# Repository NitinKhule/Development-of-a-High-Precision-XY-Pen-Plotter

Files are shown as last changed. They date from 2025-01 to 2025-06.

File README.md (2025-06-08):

## 🖊️ XY Pen Plotter – Mechatronics System Development

A functional XY Pen Plotter developed through the integration of mechanical design, embedded programming, and control system logic, following the V-model engineering lifecycle.

---

### 🛠️ Key Contributions

- ⚙️ **Mechanical Design & Fabrication**  
  ➤ Designed precise **CAD models** in SolidWorks  
  ➤ Fabricated custom parts using **3D printing** for optimized fit and high mechanical precision  

- 🧠 **Embedded System Programming**  
  ➤ Programmed the **ESP32 microcontroller** to manage:  
  - Stepper motor motion control  
  - Pen actuation routines  
  - Full system automation and calibration workflows  

- 🚧 **Hardware Optimization & Troubleshooting**  
  ➤ Solved key integration issues such as:  
  - **Wire routing and cable management**  
  - **Sensor noise filtering** for stable operation  
  ➤ Performed rigorous **testing and tuning** for consistent output quality  

- 🤝 **Multidisciplinary Collaboration**  
  ➤ Collaborated in a **cross-functional team** to:  
  - Assemble mechanical structures  
  - Design electrical circuits  
  - Fine-tune system-level performance and user interaction  

- 📐 **System Architecture – V-Model Application**  
  ➤ Followed the **V-model framework** for development:  
  - Requirements capture → Design → Implementation → Validation  
  - Ensured systematic traceability and modular development

---

### 🔧 Tools & Technologies Used
- SolidWorks (3D CAD Modeling)  
- ESP32 Microcontroller (Wi-Fi + Motion Control)  
- Stepper Motors, Drivers, and End Sensors  
- Arduino IDE · Embedded C  
- 3D Printing (PLA/FDM)  
- V-Model Software Development Lifecycle

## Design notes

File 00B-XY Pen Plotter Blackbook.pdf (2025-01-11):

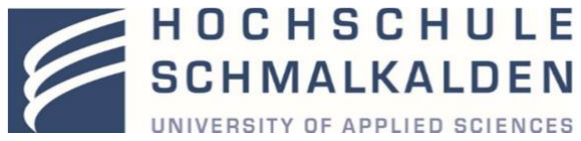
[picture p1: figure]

Schmalkalden University of Applied Sciences

Project Report on
XY- Pen Plotter

In partial fulfilment of the requirements for the degree of

Master of Engineering in
Mechatronics and Robotics

Under the subject of:
Workshop Mechatronics

Submitted By:

Choudhary, Prithviraj | 315448
Gangiredla, Varun Kumar | 315461
Khule, Nitin | 315513
Pandaraboyana, Dheeraj Kumar | 315535
Rao, Parul Vivek Sunder | 315476

Department of Mechanical Engineering Schmalkalden University of Applied Sciences Blechhammer 9, 98574 Schmalkalden

Dec 2023

CERTIFICATE

This is to certify that the project titled “XY Pen plotter” submitted by Choudhary Prithviraj, Gangiredla Varun Kumar, Khule Nitin, Pandaraboyana Dheeraj Kumar, Rao Parul Vivek Sunder; to the Mechanical Engineering Department of Schmalkalden University of Applied Sciences, in partial fulfilment of the requirements for the award of the degree of Master of Engineering in Mechatronics and Robotics is a record of our own work.

To the best of my knowledge, this report has not been submitted to any other University or Institute for award of any degree.

Choudhary, Prithviraj | 315448
Gangiredla, Varun Kumar | 315461
Khule, Nitin | 315513
Pandaraboyana, Dheeraj Kumar | 315535
Rao, Parul Vivek Sunder | 315476

This is to certify that the statements made by the candidate are correct to the best of our knowledge and belief. It is further understood that by this certificate the undersigned do not endorse or approve any statement made, opinion expressed or conclusion drawn herein, but approve the report only for the purpose for which it is submitted.

Countersigned:

Prof. Dr.-Ing. Stefan Roth, Professur Produktentwicklung / Konstruktion
Angewandte Kunststofftechnik (AKT), Fakultät Maschinenbau, Hochschule Schmalkalden,
Blechhammer 9, 98574 Schmalkalden

Prof. Dr.-Ing. Silvio Bachmann, Assistant Professor & Coordinator, Fakultät Elektrotechnik,
Hochschule Schmalkalden,
Blechhammer 9, 98574 Schmalkalden

ACKNOWLEDGEMENT

It gives us immense pleasure to express deep sense of gratitude to our supervisors

Prof. Dr.-Ing. Silvio Bachmann & Prof. Dr. Stefan Roth, for their whole hearted

and invaluable guidance throughout the project work. Without their sustained and

sincere effort, this project work would not have taken this shape. They encouraged and

helped us to overcome various difficulties that we have faced at various stages of our

project work.

We would like to take this opportunity to thank our teachers for providing a great

support and education to us in completing our workshop and for giving us the

opportunity to complete the project.

We would also like to thank our colleagues in our class because it was a great

experience to interact with them and their doubts in the class made us understand

the subject better. Last but not the least, many thanks to all group members, we

together had an amazing experience where we learned from each other, which at last

gave us great results.

Finally, we would like to thank all of our friends, family members and almighty for

their continuous help and encouragement.

TABLE OF CONTENTS

List of Figures | Pg. No.
Figure 1.1 Pen Plotter | 7
Figure 2.1 Nikolaus Haus | 8
Figure 2.2 Organisation Chart | 9
Figure 2.3 V-Model | 11
Figure 2.4 Morphological Chart | 12
Figure 3.1 DC Motor | 13
Figure 3.2 ESP32 Board | 13
Figure 3.3 L298N Motor Driver | 13
Figure 3.4 Linear Ball Bearing | 14
Figure 3.5 Pulley | 14
Figure 3.6 Adapter | 14
Figure 3.7 GT2 Belt | 14
Figure 3.8 Fastener | 15
Figure 3.9 Limit Switch | 15
Figure 3.10 MOSFET Switch | 15
Figure 3.11 Hall Sensor | 16
Figure 3.12 DC-DC Voltage Converter | 16
Figure 3.13 Kill Switch | 16
Figure 3.14 Electric Circuit Diagram | 17
Figure 3.15 Electronic Enclosure | 18
Figure 3.16 CAD Design | 19
Figure 3.17 Pen Holder | 20
Figure 3.18 End Effector | 20
Figure 3.19 Foot Design | 21
Figure 3.20 DC Motor Mount | 21
Figure 3.21 Pully Mount | 22
Figure 3.22 Sliding Pully Mount | 22
Figure 3.23 Storage Compartment | 23
Figure 4.1 3D Printer | 24
Figure 4.2 Test Piece | 25
Figure 4.3 Wires and Cables | 26
Figure 4.4 Raw v/s Filtered Data | 27

List of Tables | Pg. No.
Table 2.1 Project Timeline | 10
Table 5.1 Verification Protocol | 29
Table 5.2 Verification Report | 31
Table 5.3 Validation Protocol | 32
Table 5.4 Validation Report | 33
Table 6.1 Bill of Material | 35

## 1. INTRODUCTION

1.1 OBJECTIVES

We take great pleasure in presenting the comprehensive project report documenting our group's remarkable achievement in the development of a pen plotter. Our endeavour was dedicated to the creation of a sophisticated pen plotter capable of producing intricate drawings, with a specific emphasis on the renowned Nikolaus Haus. This project report meticulously details our journey, providing an exhaustive account of the design process, implementation strategies, testing protocols, and the successful realization of our pen plotter project.

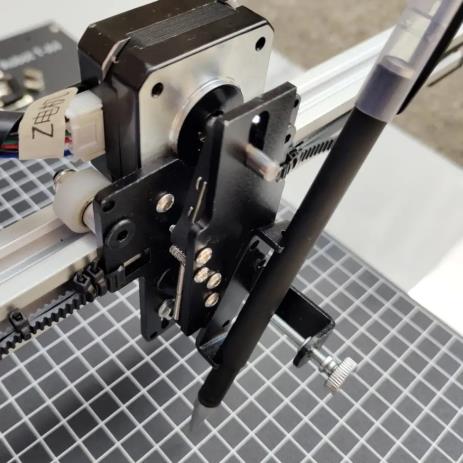
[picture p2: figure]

Figure 1.1 Pen Plotter

The Nikolaus Haus, renowned for its complex architectural details and artistic significance, posed a compelling challenge. Our sole objective was to engineer a pen plotter capable of faithfully reproducing the intricate features of the Nikolaus Haus.

The design phase involved a thorough exploration of hardware, software, and mechanical components. We meticulously selected motors, sensors, and control mechanisms to ensure optimal accuracy and control. Our software development efforts focused on designing and implementing sophisticated algorithms capable of interpreting drawing sequences and translating them into precise pen movements.

Testing and evaluation played a pivotal role in validating the performance of our pen plotter. Rigorous tests were conducted to measure accuracy, speed, and overall capability in recreating the Nikolaus Haus. Through detailed analysis of test results and iterative improvements, we ensured that our pen plotter consistently delivered exceptional results, capturing the essence of the Nikolaus Haus in each stroke.

This project report offers an in-depth narrative of our journey, elucidating the design process, implementation strategies, testing methodologies, and the final outcome of our pen plotter project. It stands as a testament to our commitment to innovation, precision, and admiration for architectural marvels that serve as sources of inspiration. We aspire for our work not only to contribute to the advancement of pen plotting but also to ignite further exploration and creativity in the realms of architectural representation and artistic expression.

## 2. PROJECT GOALS AND PROJECT PLANNING

2.1 PROJECT GOALS AND OBJECTIVES

The main goal of this project is to construct and advance a pen plotter by integrating various components responsible for governing pen movement and ensuring precise plotting on paper. The project team will engage in tasks such as designing, fabricating, and assembling the pen plotter, programming the control system, and establishing a user-friendly interface. The key activities encompass:

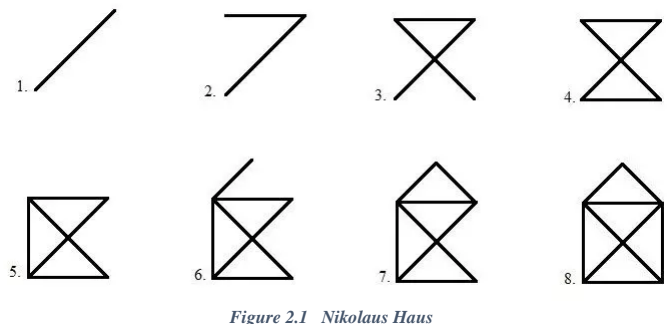
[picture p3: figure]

Figure 2.1 Nikolaus Haus

- Identifying user requirements and subsequently formulating technical and design specifications.
- Executing hardware, software, electrical, and mechanical CAD designs.
- Creating a user interface to manage pen movement.
- Conducting thorough testing and calibration of the pen plotter to achieve optimal performance.
- Demonstrating the pen plotter's functionality and showcasing its output through plotted designs, with a specific focus on Nikolaus Haus.

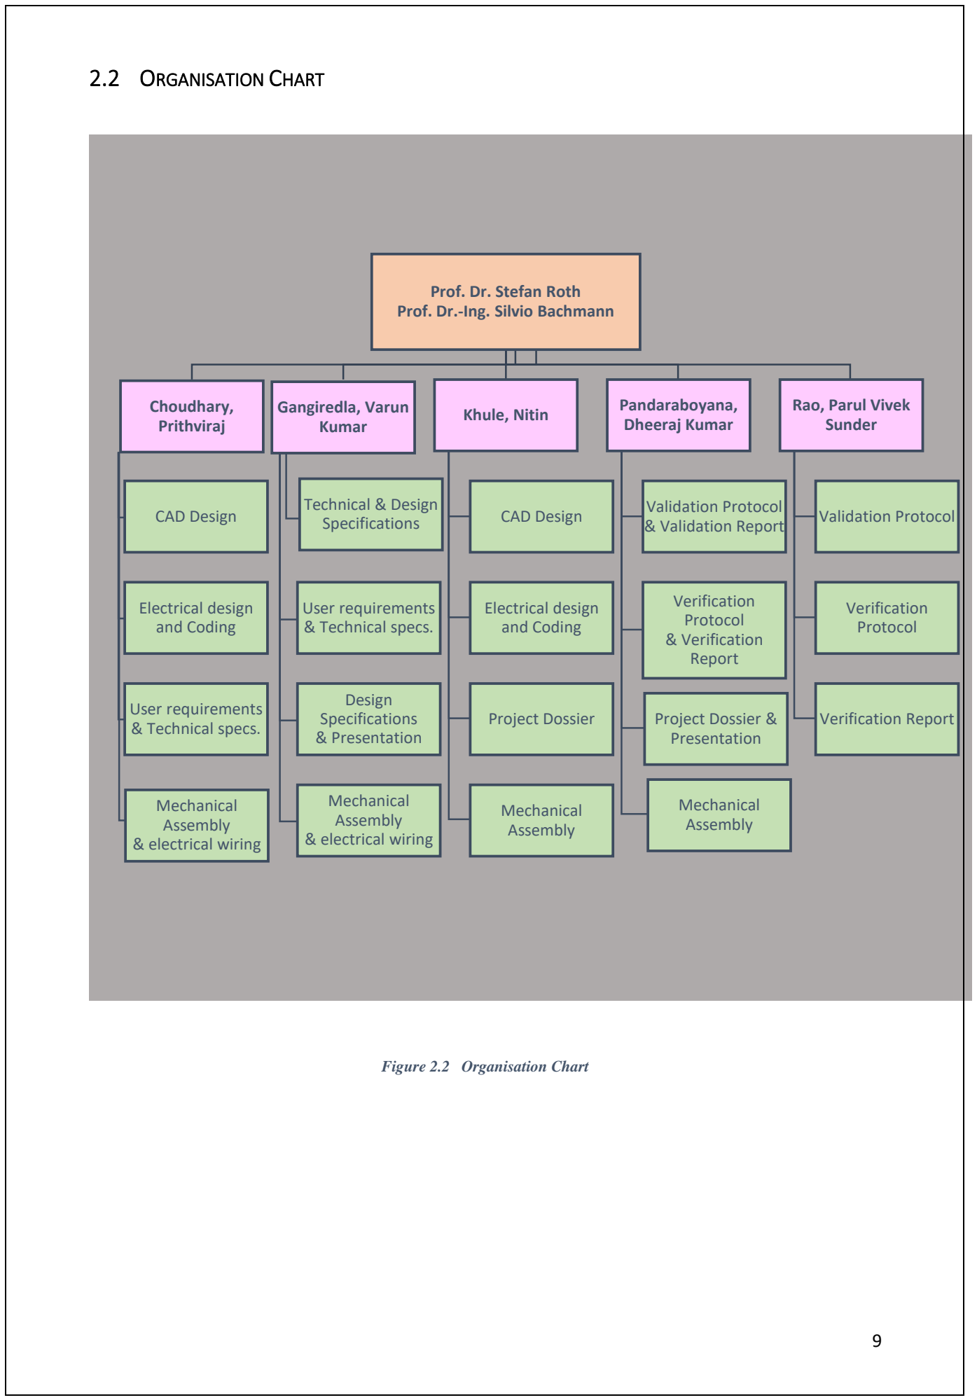
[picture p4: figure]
2.2 ORGANISATION CHART; Figure 2.2 Organisation Chart; Prof. Dr. Stefan Roth Prof. Dr.-Ing. Silvio Bachmann; Choudhary, Prithviraj; CAD Design; Electrical design and Coding; User requirements & Technical specs.; Mechanical Assembly & electrical wiring; Gangiredla, Varun Kumar; Technical & Design Specifications; Design Specifications & Presentation; Khule, Nitin; Project Dossier; Mechanical Assembly; Pandaraboyana, Dheeraj Kumar; Validation Protocol & Validation Report; Verification Protocol & Verification Report; Project Dossier & Presentation; Rao, Parul Vivek Sunder; Validation Protocol; Verification Protocol; Verification Report

2.3 PROJECT TIMELINE
The project timeline for the pen plotter is structured into several phases, encompassing research and design, component acquisition, prototyping, testing, and final implementation.

Table 2.1 Project Timeline

Phase | Tasks | Days | Start Date
Idea Phase | | 7 | 17.04.23
| Conduct market research | 2
| Benchmark models of seniors in the lab | 1
| Brainstorm for the integration of new features | 3
| Set user requirements | 1
| Completion of the idea phase with the deliverable of user requirements | 0
Project Planning | | 6 | 24.04.23
| Budget and Resource Planning | 1
| Set-Up Project Team | 1
| Develop technical specifications | 2
| Formulate design specifications | 2
| Completion of the project planning phase | 0
Development Phase | | 34 | 02.05.23
| Concept Development | 2
| Electrical Design | 2
| Software Design | 18
| Mechanical / CAD Design | 12
| Completion of CAD model and electrical circuit diagram | 0
Prototyping & Fabrication | | 14 | 03.09.23
| 3D printing of test piece for fitment | 2
| Test piece printing and checking | 1
| 3D printing of plastic parts | 6
| Assembly | 2
| Electrical Wiring | 3
| Completion of the prototype | 0
Testing and calibration | | 17 | 17.09.23
| Programming and Troubleshooting | 6
| X and Y Axis calibration | 3
| Testing drawing performance and tuning PID | 4
| Formulation of verification protocol and report | 2
| Formulation of validation protocol and report | 2
| Completion of testing and calibration | 0
Documentation | | 5 | 04.10.23
| Project Presentation | 5
| Project Dossier | 5
| Bill of material | 1
| Completion of documentation | 0

2.4 DEVELOPMENT OF DOCUMENTATION ACCORDING TO V-MODEL

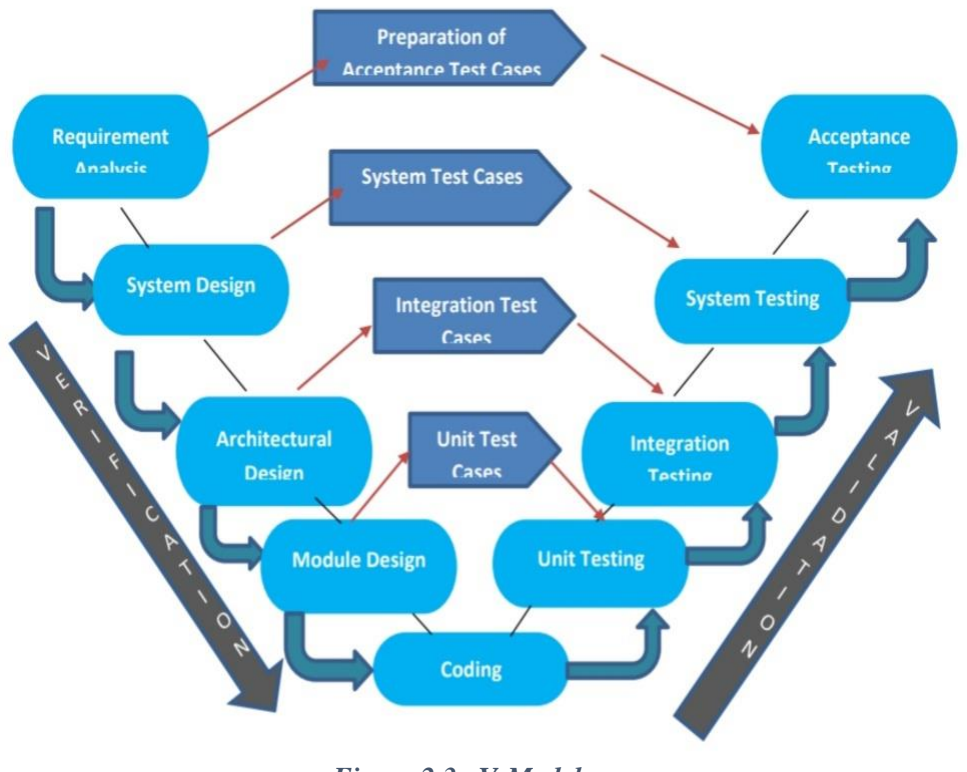
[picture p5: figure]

Figure 2.3 V-Model

The V-model for the pen plotter project offers a comprehensive framework, ensuring a systematic and structured development process. Commencing with the User Requirement stage, specific needs and expectations are gathered and documented, laying the groundwork for subsequent phases. The Technical Specification stage defines detailed specifications, covering size, resolution, speed, and accuracy. Software Requirements identify necessary functionalities, user interface design, and programming needs.

Mechanical Requirements specify components, materials, and design considerations for the pen plotter's physical structure. The Electrical Requirements stage determines electrical components, circuitry, and power requirements.

Moving into the Implementation stage, the pen plotter system is built, involving the assembly of mechanical and electrical components, integration of control systems, and software development. In the System Integration stage, individual subsystems are combined and tested for proper interaction and functionality.

The Verification of Design stage includes rigorous testing to ensure the pen plotter design aligns with specified requirements. System Testing validates overall performance, functionality, and reliability under various conditions. The Test Report documents results and findings from system testing, including encountered issues and resolutions.

Ultimately, the completed and tested XY Pen Plotter is ready for deployment and use. Adhering to the V-model ensures a systematic and thorough development approach, resulting in a reliable and high-quality pen plotter system.

2.5 MORPHOLOGICAL CHART:

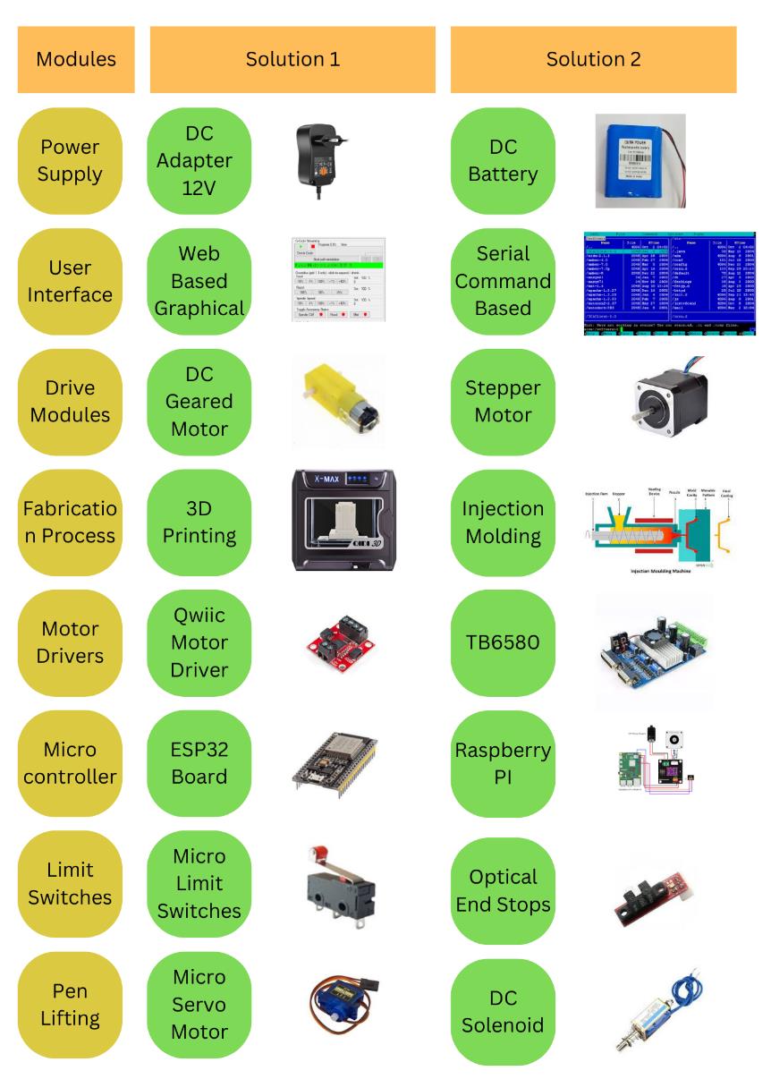
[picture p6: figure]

Figure 2.4 V-Model

The morphological chart for the pen plotter project is a visual tool that presents various design options and their corresponding features. It helps in systematically exploring and selecting components such as motors, controllers, sensors, pens, and user interface elements.

Through pairwise comparison, each design concept underwent systematic evaluations against others. As per the given set of components and best suitable components as per design requirements, we had opted for the design with Solution 2.

## 3. DESIGN STAGE

3.1 COMPONENT SELECTION

1- D.C. Motor: Two DC motors play a crucial role in a pen plotter project by providing precise rotary motion. This controlled movement of the motors allows for accurate pen positioning, facilitating precise plotting and drawing on a variety of surfaces.

Figure 3.1 D.C. Motor

2-ESP32 Board: ESP32 board used in pen plotter project versatile microcontroller with built-in Wi-Fi and Bluetooth, providing wireless connectivity and control for precise pen plotting and automation.

Figure 3.2 ESP32 Board

3-L298N Motor: The L298N Motor Driver is employed in a pen plotter project as a dual H-bridge module, responsible for regulating both motor speed and direction. This utilization ensures accurate control over the movement and positioning of the pen within the plotter, contributing to precise plotting and drawing outcomes.

Figure 3.3 L298N Motor Driver

4- Linear Ball Bearings: Linear ball bearings are implemented in the pen plotter project as rolling element bearings. These components facilitate smooth and low-friction linear motion, guaranteeing the precise and stable movement of the plotter carriage along the rails.

Figure 3.4 Linear Ball Bearing

5- Geared Pulley: In the pen plotter project, a pulley serves as a mechanical component with grooves, enabling the smooth and controlled rotation of belts or cables. This functionality ensures accurate pen positioning and movement within the plotter system.

Figure 3.5 Pulley

6-Adapter 12V (DC Power): The 12V DC Adapter employed in the pen plotter project serves as a power source, delivering regulated power to the plotter system. This ensures the stable and reliable operation of the various components and motors within the system.

Figure 3.6 Adapter

7-GT2 Driver Belt: In the pen plotter project, the GT2 driver belt is utilized as a high-quality toothed belt. This component plays a crucial role in enabling precise and synchronized movement by transferring rotational motion to linear motion with minimal backlash.

Figure 3.7 GT2 Belt

8-Screws and Fasteners: In the pen plotter project, screws and fasteners play a vital role by securely fastening components. This ensures the structural integrity of the system and precise alignment, contributing to stable and accurate operation of the plotter.

Figure 3.8 Fastener

9-Micro Limit Switch: The Micro Limit Switch incorporated into the pen plotter project is a small, mechanical switch with precise actuation. This component plays a key role in providing accurate end stop detection, contributing to precise pen movement control and ensuring accurate positioning in the plotter system.

10-MOSFET Switch: MOSFET Switch used in pen plotter project electronic switch with high switching speed and low power dissipation, enabling efficient control of motor and other high-current devices in the plotter system.

Figure 3.10 MOSFET Switch

11-49E Hall Sensor: 49E Hall sensor used in pen plotter project magnetic field sensor detecting changes in magnetic field intensity, providing feedback for precise position sensing and control in the plotter system.

Figure 3.9 Limit Switch

Figure 3.11 Hall Sensor

12-DC-DC Voltage Converter: DC-DC voltage converter used in pen plotter project converts input voltage to desired output voltage, providing power flexibility and stability for various components in the plotter system.

Figure 3.12 DC-DC Voltage Converter

13-Push Button: Push button (kill switch) used in pen plotter project emergency stop button for immediate system shutdown, ensuring operator safety and preventing potential accidents during operation.

Figure 3.13 Kill Switch

3.2 ELECTRICAL DESIGN

The electrical schematic diagram illustrates the well-structured design of a pen plotter project, showcasing the efficient interconnection of key components. At the heart of the circuit is the ESP32 microcontroller, functioning as the main controller to independently manage X and Y axis motors through L298N motor drivers. These drivers ensure precise motor control, facilitating smooth and accurate pen movements for precise drawings.

For vertical pen motion control, a 12V DC solenoid with a 5N force is integrated. Activated selectively by the microcontroller, the solenoid accurately raises or lowers the pen onto the plotting surface, allowing precise positioning for drawing or lifting to prevent unintended marks.

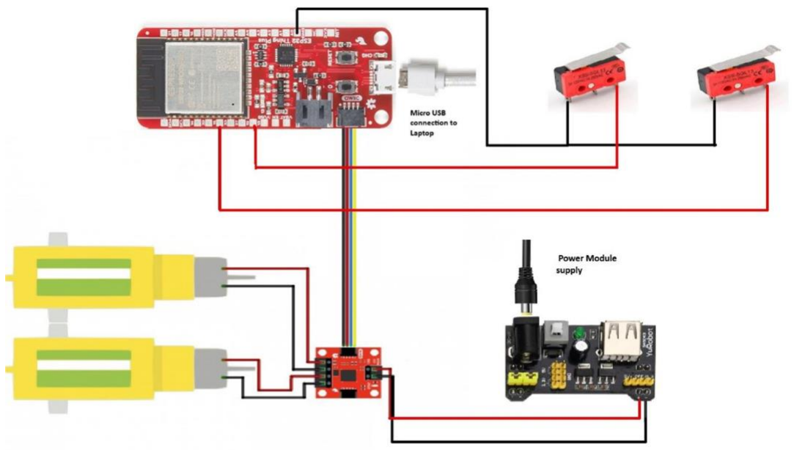
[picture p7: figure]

Figure 3.14 Electric Circuit Diagram

To provide operational feedback, a 0.96-inch OLED display is incorporated, offering a clear interface for real-time updates on drawing progress, error messages, and user prompts. Enhancing the user experience, the display facilitates interaction with the plotter.

The inclusion of four Hall sensors serves as encoders, providing precise position feedback by detecting and measuring magnetic fields. This feedback loop ensures accurate plotting, enabling the creation of intricate designs.

For safety and boundary enforcement, strategically placed limit switches in the X-Y plane halt the pen plotter's movement upon reaching predefined limits. These switches trigger the microcontroller, adding an extra layer of safety to prevent damage.

Unlike a breadboard, the circuit is constructed on a perf-board, eliminating signal noise risks from loose connections. This choice ensures the reliable and stable operation of the pen plotter, providing a secure platform for component assembly and contributing to the overall robustness of the system.

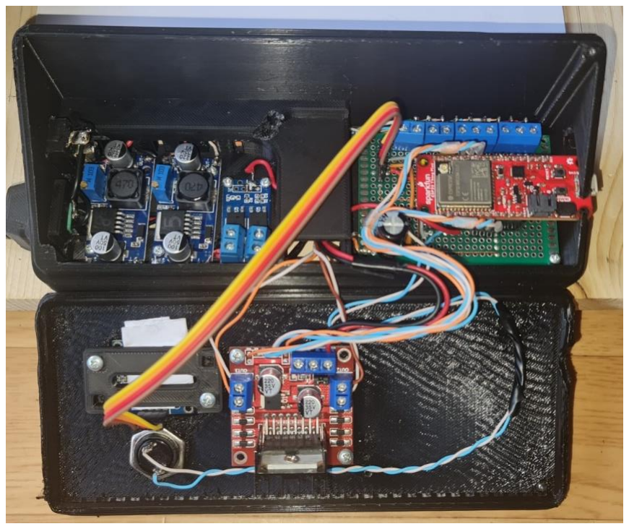
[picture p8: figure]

Figure 3.15 Electronic Enclosure

In summary, the electrical schematic diagram offers a comprehensive configuration for a pen plotter project, leveraging the integration of key components to enable precise control, accurate plotting, and improved reliability. This results in the creation of intricate and high-quality drawings.

3.3 MECHANICAL CAD DESIGN

As per requirements, the planning phase regarding the design was done and the below procedure was followed: Initially, the following components were designed accurately by using DSS SolidWorks:

a) Frame and Structure
b) Carriage and Slides
c) Pulley and its fixtures
d) Pen Holder

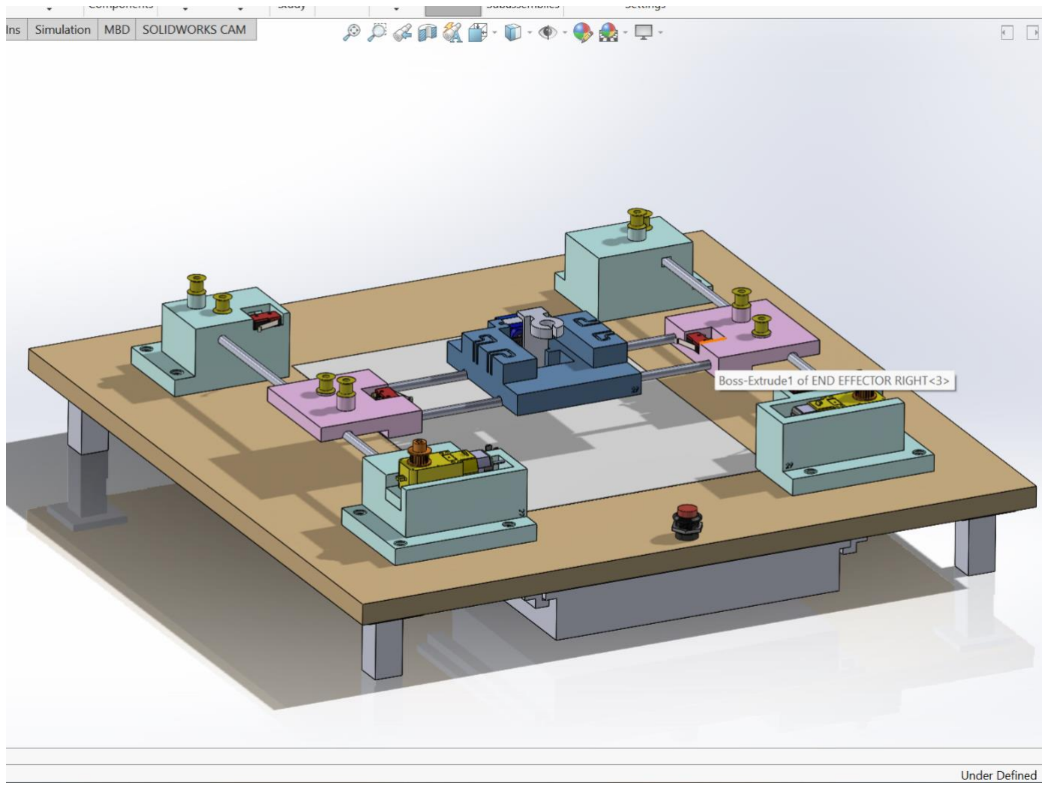
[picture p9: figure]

Figure 3.16 CAD Design

1-Pen holder: It is a mechanical component designed to securely hold the pen, enabling controlled and precise movement during plotting. It accommodates different pen sizes, allows for quick pen changes, and ensures consistent pen pressure for accurate and smooth drawings.

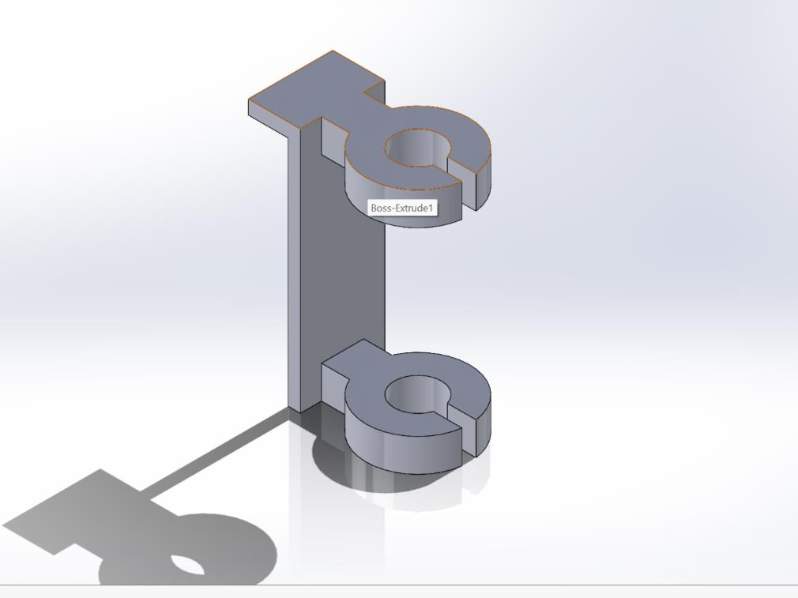
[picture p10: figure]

Figure 3.17 CAD Design

2-End Effector: The pen plotter's end effector should securely hold adjustable pens, maintain precise positioning, adapt to various drawing surfaces, be lightweight for efficient movement, integrate seamlessly with the plotter frame, include a reliable pen lifting mechanism, and offer a feedback system for improved control. Prioritize ease of maintenance and part replacement.

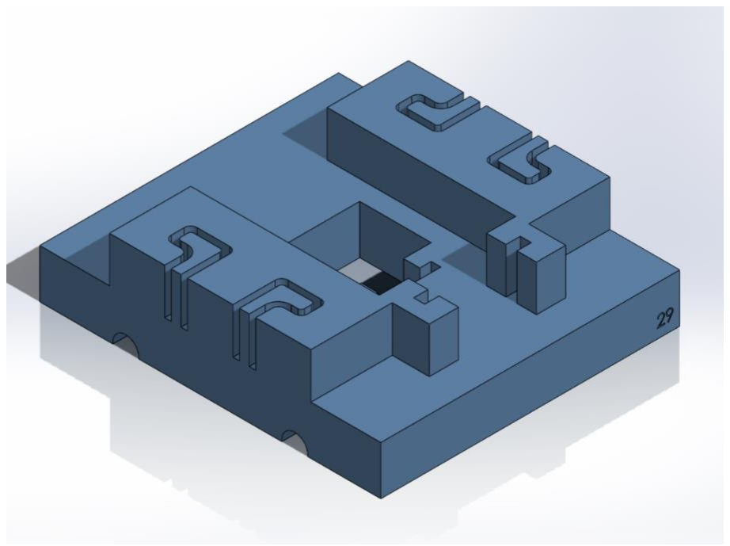
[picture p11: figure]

Figure 3.18 End Effector

3-Foot: The foot design in a pen plotter ensures stability, vibration damping, and non-slip properties. It should be compatible with the plotter frame, allow for adjustable height, and be easy to install. Durable materials contribute to longevity, and considerations for portability may also be relevant.

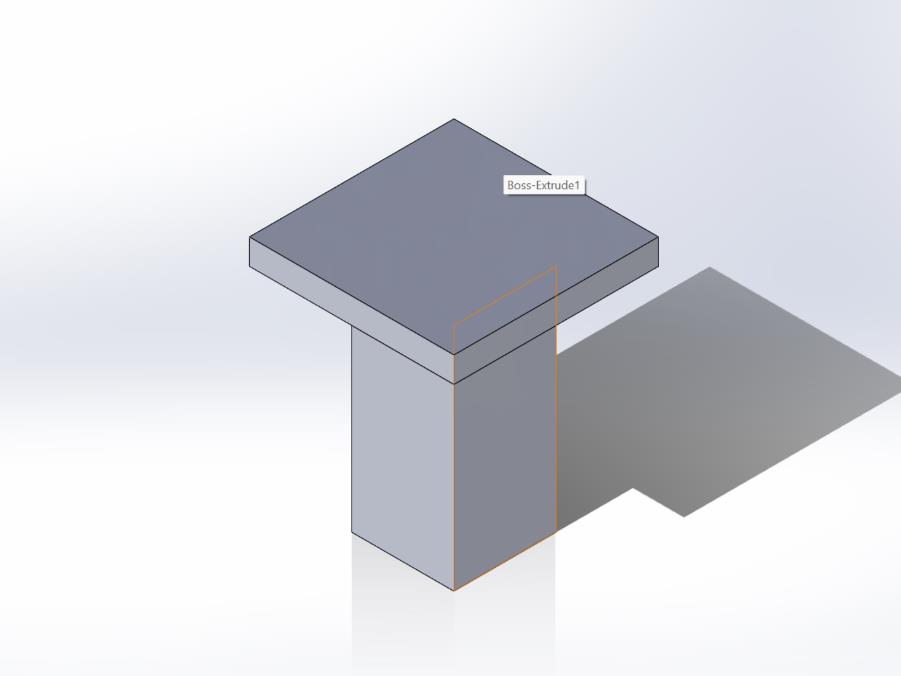
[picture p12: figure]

Figure 3.19 Foot Design

4-DC Motor Mount: The DC motor mount in a pen plotter design secures the motor in place, ensuring stable and precise movements. It is typically engineered to integrate seamlessly with the plotter structure, providing reliability and facilitating ease of assembly. The design should consider factors such as vibration reduction, adjustability, and compatibility with the overall plotter framework.

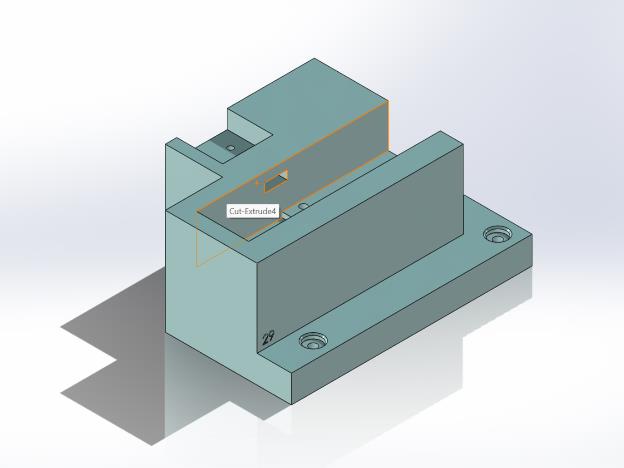
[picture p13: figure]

Figure 3.20 DC Motor Mount

5-Pully Mount: The pulley mount in a pen plotter design securely positions the pulleys for smooth and controlled movement. It is engineered for stability, compatibility with the plotter structure, and efficient power transmission. The design emphasizes precision, minimizing play, and ensuring optimal alignment for accurate plotting.

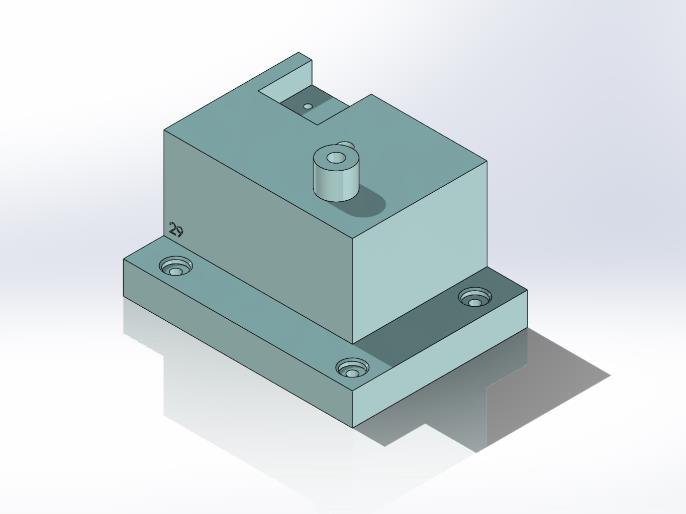
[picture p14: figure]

Figure 3.21 Pully Mount

6-Sliding pully Mount: The sliding pulley mount in a pen plotter design enables movement solely in the Y-direction. This specialized mount houses pulleys that guide the plotter mechanism, ensuring smooth and accurate motion along the vertical axis. The design prioritizes precision, minimizing play, and facilitating efficient power transmission for reliable plotting performance.

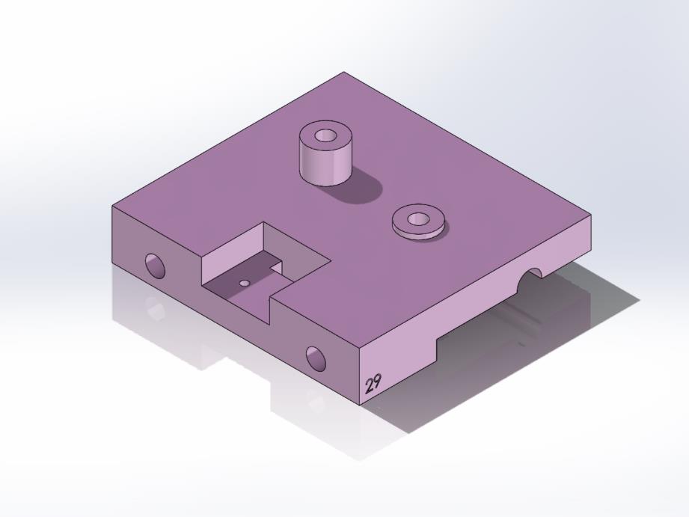
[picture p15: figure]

Figure 3.22 Sliding Pully Mount

7-Storage Compartments: The storage compartments in the XY pen plotter design house various electrical components, ensuring organized and accessible placement. These compartments are strategically integrated into the plotter structure, providing a space-efficient solution for storing components such as controllers, drivers, and wiring. The design prioritizes accessibility, allowing for convenient maintenance and troubleshooting when needed.

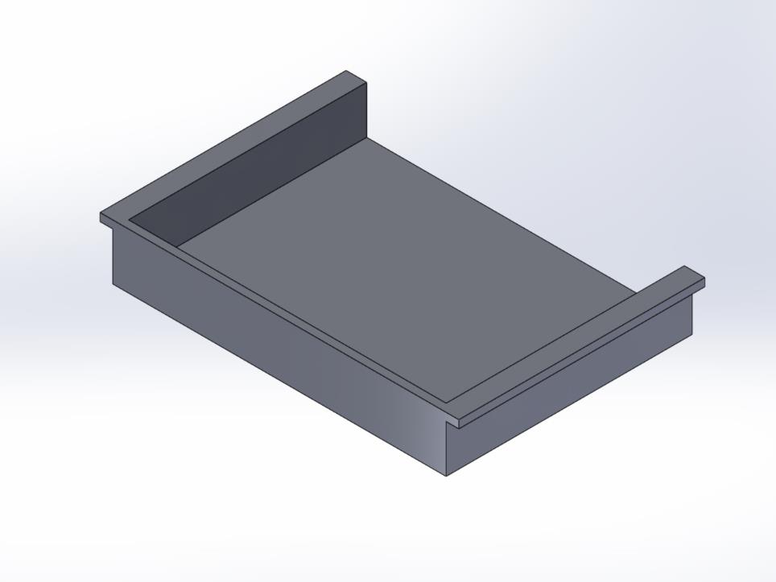
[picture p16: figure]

Figure 3.23 Storage Compartment

Base Plate: The base plate in a pen plotter project serves as the foundational chassis on which the entire assembly is mounted. Typically made of wood, it provides stability and support to the various components, ensuring a rigid structure for accurate and reliable pen plotting operations.

It provides a convenient and organized arrangement, securing and protecting these components, simplifying the wiring connections, and facilitating easy access for control and operation of the pen plotter system.

## 4. DEVELOPMENT AND FABRICATION STAGE

4.1 PROCESS USED TO DEVELOP THE PEN PLOTTER

The creation and construction phase of the pen plotter encompass the conversion of the initial concept into a fully operational device. This entails the formulation of the mechanical framework, the careful selection and incorporation of components, the production and assembly of physical elements, the thorough testing of the system to ensure functionality and accuracy, and the documentation of the entire process for future reference and enhancement.

4.2 SELECTION OF MATERIALS

PLA (Polylactic Acid) stands out as the ideal filament for beginners in the typical FDM printing procedure, owing to several key attributes. It has been selected because of its:

1. Excellent printability
2. Reduced distortion (warping) throughout the printing process.
3. User-friendly nature
4. Cost-effectiveness
5. Compatibility with 3D printing technology
6. Environmentally friendly characteristics
7. All the 3D designed components were printed using the "QIDI TECH X-MAX 3D Printer" located in the AKT lab, Haus D.

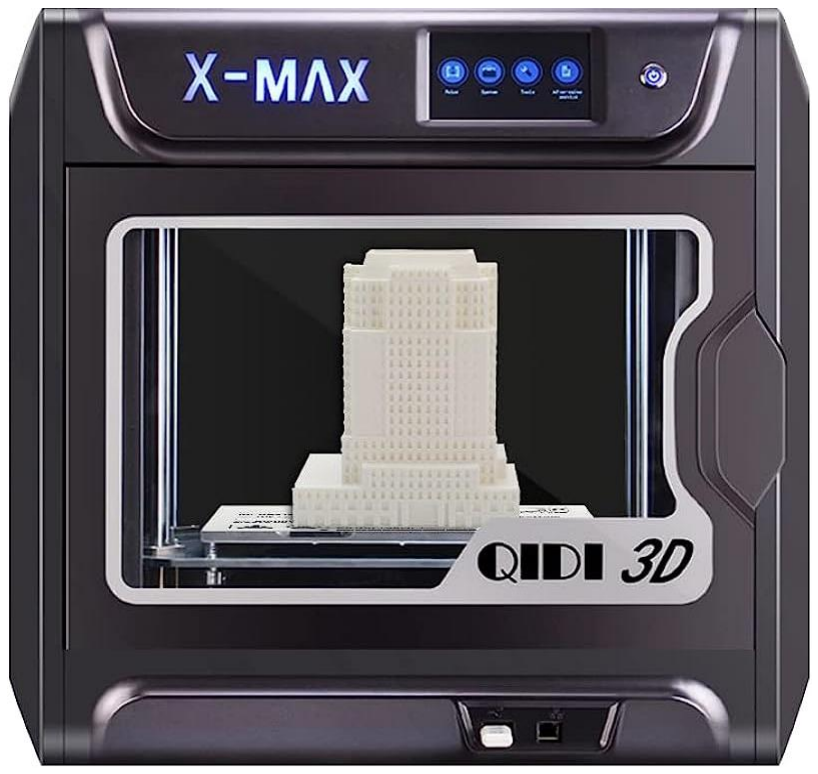
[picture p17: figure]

Figure 4.1 3D Printer

4.3 APPLICATION OF TEST PIECE

Incorporating a test piece in the 3D printing process enables the assessment of print quality, detection of potential issues, and fine-tuning of printing parameters to achieve precise tolerance and fitment before proceeding with the final part production. This practice enhances the assurance of accuracy, functionality, and compatibility, ultimately reducing errors and minimizing material and time wastage.

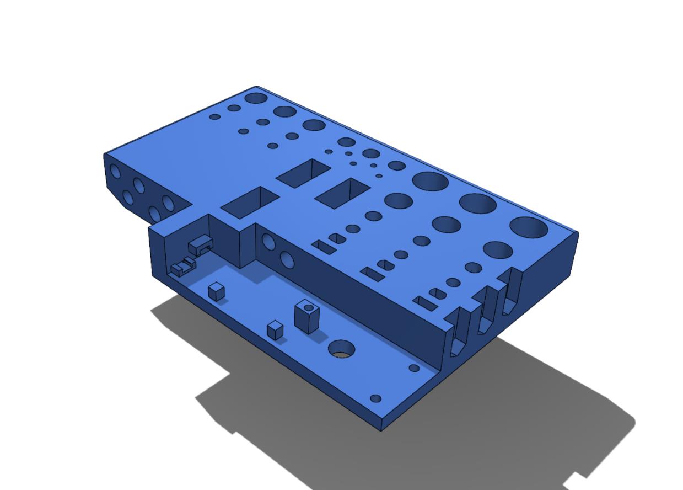
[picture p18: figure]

Figure 4.2 Application test piece

4.4 CHALLENGES FACED DURING DEVELOPMENT STAGE:

4.4.1 Challenges Regarding Wire Routing

Within electronic design, a pivotal aspect involves concealing the wiring network to elevate the visual appeal of the product. Exposed wires not only result in a disorderly and unappealing aesthetic but also compromise the overall design and professionalism of the product. Additionally, the susceptibility of exposed wires to snagging, bending, or unintentional interference can lead to electrical malfunctions or even the complete failure of the device. To address these issues, we've developed an enclosure featuring a built-in wire routing channel that adeptly accommodates all wiring connections and electronic components. The incorporation of plastic cable ribbons facilitates the organized routing of wires to the X and Y carriages, ensuring a tidy internal structure for enhanced functionality and reliability.

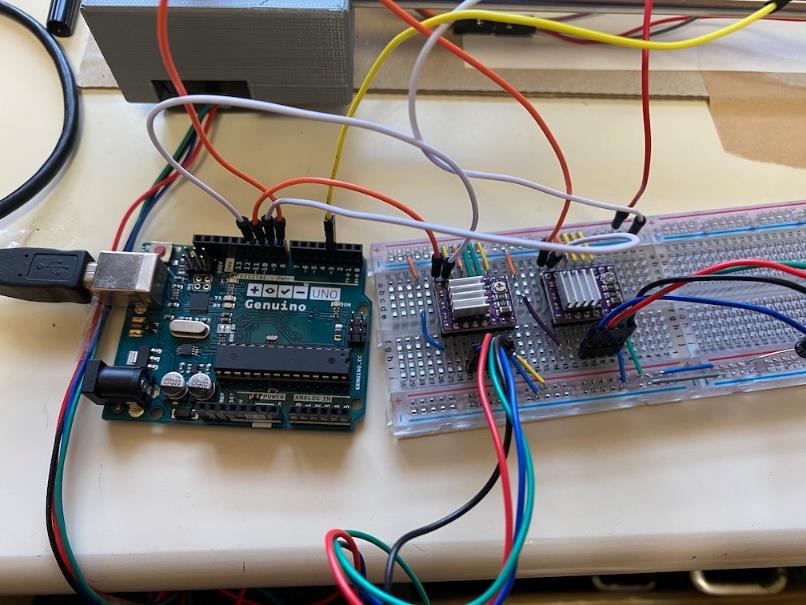
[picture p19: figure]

Figure 4.3 Wires and Cables

4.4.2 Issue associated with noise in sensor output signals poses

In our design, we have integrated Hall sensors along with a magnetic encoder disk to detect rotational changes in the magnetic field. The encoder disk features alternating magnetic poles positioned uniformly around its circumference. As these magnetic poles pass the Hall sensors, they induce voltage through the Hall effect, allowing microcontrollers to interpret position and movement. Unfortunately, the presence of noise in the sensor output signals led to inconsistencies in position sensing, resulting in inaccuracies in plot path tracking.

To address this issue, we implemented effective wiring techniques, such as using twisted pair cables, to minimize ground loops and reduce noise coupling. Additionally, the incorporation of a digital Butterworth filter, a signal filtering method, proved instrumental in significantly reducing high-frequency noise components. Furthermore, we took measures to shield all wires using a Silver-Plated Copper Braid, providing protection against external electromagnetic interference. These enhancements collectively contribute to a more reliable and accurate performance of the system.

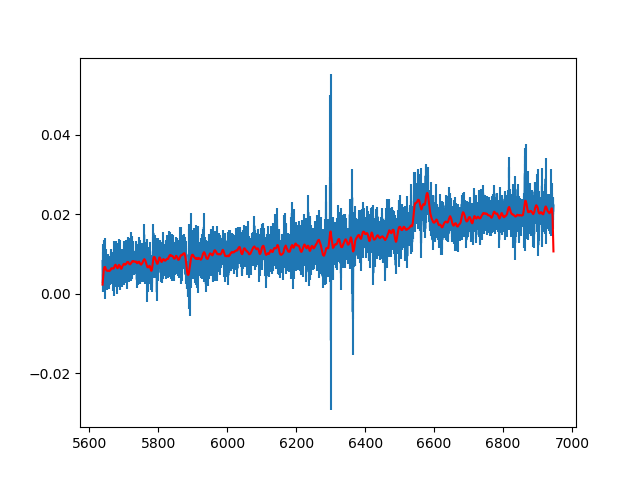
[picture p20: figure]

Figure 4.4 Raw v/s Filtered Data

## 5. TESTING AND ITERATION

The phase of testing and iteration in the development of a pen plotter project entails a comprehensive assessment of the system's functionality, performance, and reliability. This encompasses the evaluation of motion control, pen actuation, and plotter coordination. The goal is to identify any issues or limitations and implement iterative refinements to enhance the overall performance and accuracy of the project.

5.1 TESTING PROCEDURE

- Restricted Color Range: Pen plotters typically employ a single color of pen or marker, restricting the artistic use of color to monochrome or a narrow spectrum. Working solely with pen plotters may pose challenges in creating vibrant and diverse color combinations.
- Slower Speed: In comparison to alternative printing technologies, pen plotters operate at relatively slower speeds. The mechanical nature of the device, coupled with the precision required for accurate charting, constrains their efficiency for large-scale or time-sensitive tasks. This limitation can result in extended processing and plotting durations.
- Positional Accuracy: Pen plotters can utilize both DC geared motors and stepper motors. However, when employing micro-stepping, stepper motors offer superior positional accuracy compared to DC geared motors.
- Limited Media Compatibility: Pen plotters perform optimally on flat materials such as paper or cardstock. Challenges may arise when attempting to plot on unconventional or uneven surfaces. The restricted compatibility with various artistic mediums may impede experimentation and exploration.

5.2 DESIGN ITERATION

The CAD design of the pen plotter project incorporates meticulously planned cable routing paths to ensure effective cable management, thereby reducing the likelihood of cable entanglement or obstruction during operation.

The objective is to uphold a neat and organized layout while enabling the smooth movement of the plotter. Through the strategic planning of cable routes, potential issues such as interference with moving parts, signal disruptions, and overall system reliability are proactively addressed. Factors like cable length, flexibility, and secure attachment points receive careful attention to ensure optimal performance and minimize the risk of malfunctions related to cables. The design considerations underscore the significance of cable management in maintaining a streamlined and efficient operation of the pen plotter.

Table 5.1 Verification Test Protocol

Verification Protocol

VerP # ref to TS #

Test
procedure
(description of
routine)

Verification
Criterion

Ref. # (i.e. test
protocol, etc)

Domain
(HW/SW/ME/ALL)

Application

VerP1 | TS5

Setup pen plotter
on a stable
surface. Then
draw Nikolaus
house 10 times.

10 Nikolaus
Haus drawn

Group
29_Technical
Specification.xlsb

ALL

General Functions

VerP2 | TS1 | Put the pen plotter into a box of 56x42x39 cm provided by Uni Lab. | Fits in box with lid closed | Group 29_Technical Specification.xlsb | HW
VerP3 | TS1 | Place the pen plotter assembly on a measuring scale with an accuracy of ± 1gm. Take 3 readings and find out their mean value. | Mean of three weight measurement is well below 3500gm | Group 29_Technical Specification.xlsb | HW
VerP4 | TS1 | Run the Pen Plotter continuously across the paper for 30 min. | Continuous drawing upto 30 min at a time. | Group 29_Technical Specification.xlsb | ALL
VerP5 | TS1 | Start stopwatch, activate plotter with button, run stopwatch concurrently. Stop timer after drawing completion. Take 3 readings and find out their mean value. | Average Time taken <40 seconds | Group 29_Technical Specification.xlsb | ALL
VerP6 | TS1 | Move the Pen from point A (0,0) to Point B (100,100) 10 times and measure the error at Point B for each cycle. | Average error <= ± 0.24mm | Group 29_Technical Specification.xlsb | ALL

General Functions

VerP7 | TS1

Start the pen
plotter and take
noise level
measurement by
sound level
meter. Take 5
readings and
find out their
mean value.

Mean of three
noise
measurement
is <=60 dBA

Group
29_Technical
Specification.xlsb

HW/ME

Module Motor Controller Electronics and Wiring

VerP8 | TS8

Confirm switch
functionality,
halt plotter
movement when
contacted by
levers,
preventing
overtravel and
ensuring
accurate and
safe plotting.
Check 10 times.

Overtravel
prevention,
accurate and
safe plotting.

Group
29_Technical
Specification.xlsb

HW

Module Base Plate

VerP9 | TS8

Align the plotter
for accurate
plotting within
the maximum
A4 size.

Maximum size
of drawing
media = A4.

Group
29_Technical
Specification.xlsb

HW
Perform 10 test
plot using an
A4-sized
drawing media.
Module Pen Holder / Carriage
VerP10 | TS8 | Gather pens, position them and measure the diameter by Vernier callipers. Record the measurement results for each pen. | The diameter is less than 15mm | Group 29_Technical Specification.xlsb | ME
VerP11 | TS8 | Drawing media is positioned correctly, and maximum thickness of drawing media (wood base, etc) 3cm. | Maximum thickness of drawing media = 3cm. | Group 29_Technical Specification.xlsb | HW/ME

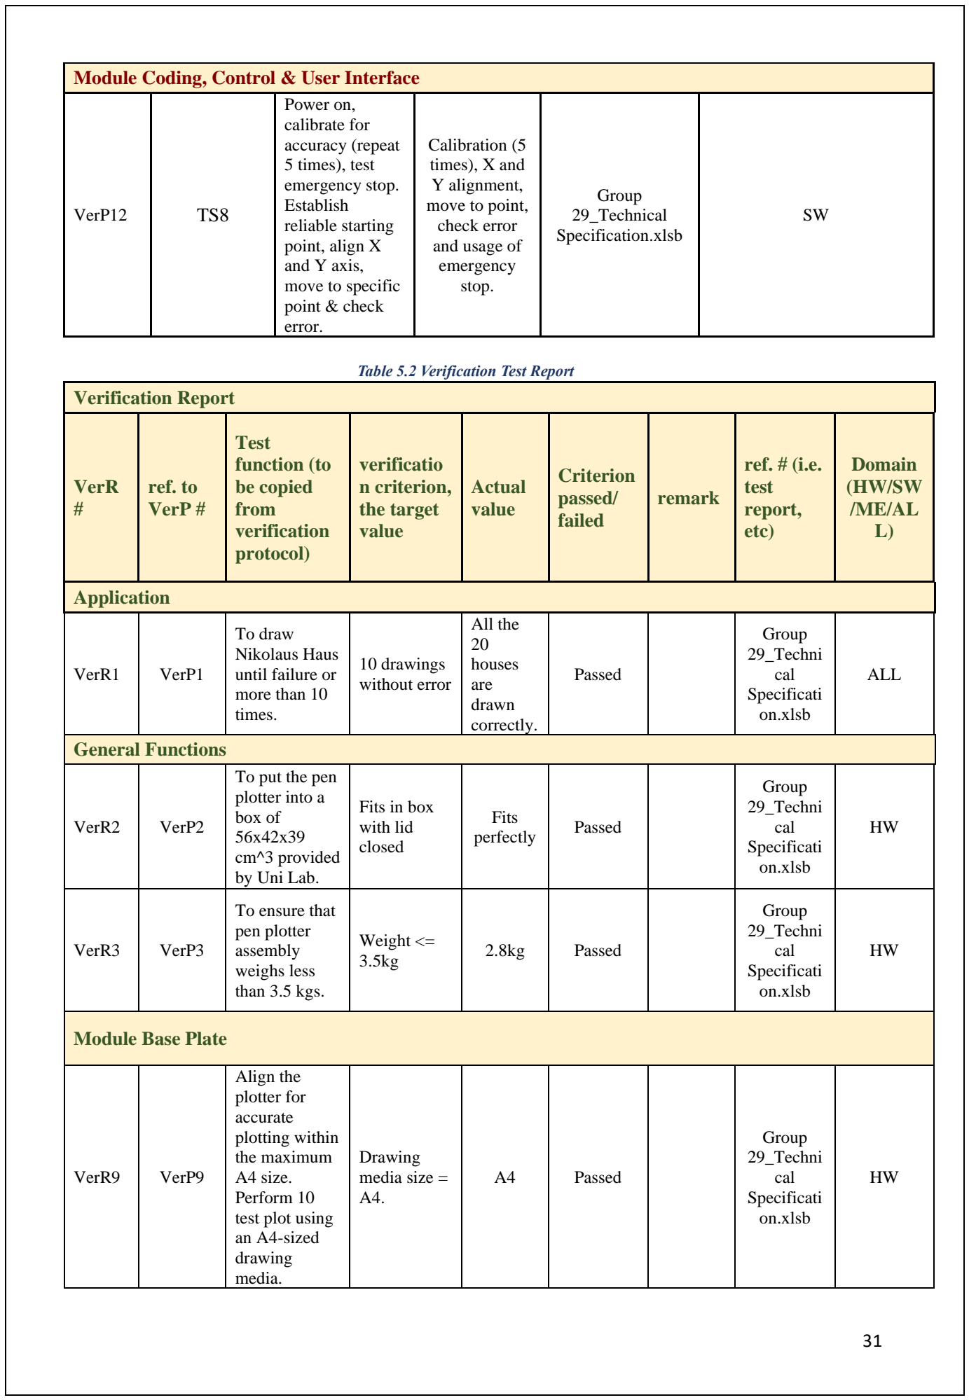
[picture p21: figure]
Table 5.2 Verification Test Report; Module Coding, Control & User Interface; VerP12; Power on, calibrate for accuracy (repeat 5 times), test emergency stop. Establish reliable starting point, align X and Y axis, move to specific point & check error.; Calibration (5 times), X and Y alignment, move to point, check error and usage of emergency stop.; Group 29_Technical Specification.xlsb; Verification Report; VerR #; ref. to VerP #; Test function (to be copied from verification protocol); verificatio n criterion, the target value; Actual value; Criterion passed/ failed; remark; ref. # (i.e. test report, etc); Domain (HW/SW /ME/AL L); Application; VerR1; VerP1; To draw Nikolaus Haus until failure or more than 10 times.; 10 drawings without error; All the 20 houses are drawn correctly.; Passed; Group 29_Techni cal Specificati on.xlsb; ALL; General Functions; Module Base Plate; VerR9; VerP9; Align the plotter for accurate plotting within the maximum A4 size. Perform 10 test plot using an A4-sized drawing media.; Drawing media size = A4.

VerR2 | VerP2 | To put the pen plotter into a box of 56x42x39 cm^3 provided by Uni Lab. | Fits in box with lid closed | Fits perfectly | Passed | Group 29_Techni cal Specificati on.xlsb | HW
VerR3 | VerP3 | To ensure that pen plotter assembly weighs less than 3.5 kgs. | Weight <= 3.5kg | 2.8kg | Passed | Group 29_Techni cal Specificati on.xlsb | HW

Table 5.3 Validation Test Protocol

Module Pen Holder / Carriage

VerR10 | VerP10 | Maximum pen diameter used is less than or equal to 15mm | Diameter <=15mm | 13mm | Passed | Group 29_Techni cal Specificati on.xlsb | ME
VerR11 | VerP11 | Determine the max. Permissible Drawing media thickness | Maximum thickness of drawing media >= 5mm. | 3cm | Passed | Group 29_Techni cal Specificati on.xlsb | HW/ME

Module Coding, Control & User Interface

VerR12 VerP12

Start,
Calibrate (5x),
Test
Emergency
Stop. Establish
starting point,
Align X and
Y, Move to
point, Check
error.

Execute all
the given
tasks/functio
ns.

All the
functions
were
working
properly.

Passed

Group
29_Techni
cal
Specificati
on.xlsb

SW

Validation Protocol

ValP # | ref. to UR # | Validation procedure (description of routine) | ref. # (i.e. validation protocol, customer test, etc.) | Validation criterion, target value
ValP1 | UR1, UR2, | Install the pen plotter in the university lab, initiate the pen plotter under the student's supervision, and proceed to create a drawing of Nikolaus Haus. | Group 29_Technical Specification.xlsb | Plotter must draw Nikolaus Haus in one run.

Table 5.4 Validation Test Report

ValP # | ref. to UR # | Validation procedure (description of routine) | ref. # (i.e. validation protocol, customer test, etc.) | Validation criterion, target value
ValP2 | UR3 | Put the pen plotter into a box of 56x39x42 cm provided by Uni Lab. | Group 29_Technical Specification.xlsb | Fits perfectly
ValP3 | UR4 | Place the pen plotter assembly on a measuring scale with an accuracy of ± 1gm | Group 29_Technical Specification.xlsb | Total weight <= 3.5kg
ValP4 | UR3 | Continuous drawing up to 30 min at a time. | Group 29_Technical Specification.xlsb | 30 min.
ValP5 | UR4 | Compare the calculated mean value with expected results or specifications to ensure the accuracy of the timing measurements. | Group 29_Technical Specification.xlsb | Average error <= ±0.25mm
ValP6 | UR4 | Start the pen plotter and take noise level measurement by sound level meter. | Group 29_Technical Specification.xlsb | Average noise measure <=60 dBA

Validation Report

ValR # | ref. to ValP #

Criteria
ref. # (i.e. test report, etc..) (passed/failed)
ValR1 | ValP1 | Passed | Group 29_Technical Specification.xlsb
ValR2 | ValP2 | Passed | Group 29_Technical Specification.xlsb
ValR3 | ValP3 | Passed | Group 29_Technical Specification.xlsb
ValR4 | ValP4 | Passed | Group 29_Technical Specification.xlsb
ValR5 | ValP5 | Passed | Group 29_Technical Specification.xlsb
ValR6 | ValP6 | Passed | Group 29_Technical Specification.xlsb
ValR7 | ValP7 | Passed | Group 29_Technical Specification.xlsb
ValR8 | ValP9 | Passed | Group 29_Technical Specification.xlsb
ValR9 | ValP10 | Passed | Group 29_Technical Specification.xlsb

´

## 6. CONCLUSION AND ACKNOWLEDGEMENTS

In summary, the realization of our pen plotter project exemplifies the seamless integration of a diverse array of components. This achievement stands as a testament to the dedication, expertise, and collaborative spirit of our team. The incorporation of key elements, including DC motors, an ESP32 board for efficient control, a DC-DC converter for optimized power management, a Hall sensor and encoder for precise positioning, a linear ball bearing for smooth pen movement, pulleys for accurate belt drive, a DC solenoid for pen lifting, an OLED display for intuitive user interaction, and micro limit switches for reliable end stop detection, has resulted in the development of a high-performance and user-friendly pen plotter.

We express our sincere gratitude to all those who contributed to the success of this project. Our thanks extend to the team members who diligently worked on every facet, from design to implementation, ensuring the pen plotter's functionality and performance. Additionally, we acknowledge the invaluable support and guidance provided by our mentors and advisors throughout the project's development.

The accomplishment of this pen plotter project not only marks the realization of a creative and functional tool but also opens up new avenues for artistic expression and design. We anticipate further refinement and expansion of its capabilities in the future.

6.1 BILL OF MATERIALS

Table 7.1 Bill of Material

## Bill of Materials

Item | Description | Material | Source | QTY | Measurement | Unit Price
Total
Price
Mechanical Components
M01 | Guiding Shaft 6mm | Steel | University Lab | 4 | Piece | € 3.00 | € 12.00
M02 | Timing Belt GT2 | Nylon | University Lab | 1.2 | meter | € 2.06 | € 2.47
M03 | M3 Nut | Steel | Hellweg | 20 | Piece | € 0.10 | € 1.99
M04 | M3 Bolt | Steel | Hellweg | 7 | Piece | € 0.09 | € 0.60
M05 | M4 Nut | Steel | University Lab | 5 | Piece | € 0.10 | € 0.50
M06 | M4 Bolt | Steel | University Lab | 5 | Piece | € 0.20 | € 1.00
M07 | M5 Nut | Steel | University Lab | 12 | Piece | € 0.10 | € 1.20
M08 | M5 Bolt | Steel | University Lab | 12 | Piece | € 0.20 | € 2.40
M09 | Wood screw 3.5x30 mm | Steel | Hellweg | 9 | Piece | € 0.15 | € 1.35
M10 | SS Screws M3x15mm | Steel | University Lab | 20 | Piece | € 0.06 | € 1.20
M11 | Silicon-Grease | | Amazon | 4 | gram | € 0.12 | € 0.48
M12 | Super Glue | | Amazon | 8 | gram | € 0.45 | € 3.60
M13 | 2mm Magnets | | Amazon | 60 | Piece | € 0.03 | € 1.80
M14 | 2mm Brass Rod | Brass | Hellweg | 0.5 | meter | € 2.39 | € 1.20
M15 | 6mm LMU-N6 linear bearing | | University Lab | 6 | Piece | € 1.10 | € 6.60
M16 | Tension spring 15mm | Steel | Hellweg | 2 | Piece | € 0.05 | € 0.10
| | | | | Subtotal | | € 45.59
Electrical Components
E01 | ESP32 Board | University Lab | 1 | Piece | 3.2 | 3.2
E02 | Motor Driver L298N | Amazon | 1 | Piece | 3 | 3
E03 | DC Motor 48:1 geared 6V | University Lab | 2 | Piece | 4.23 | 8.46
E04 | Limit Switch SPDT AC 250V 5A | University Lab | 4 | Piece | 1 | 4
E05 | Perf-Board 5x7cm | Amazon | 1 | Piece | 2 | 2
E06 | Screw terminals | Amazon | 6 | Piece | 0.02 | 0.12
E09 | Adaptor 12V (DC Power) | Amazon | 1 | Piece | 16.91 | 16.91
E10 | MOSFET Switch | Amazon | 1 | Piece | 1.3 | 1.3
E11 | 49E Hall Sensor | Amazon | 4 | Piece | 0.6 | 2.4
E12 | DC-DC Buck Voltage Converter | Amazon | 2 | Piece | 1.15 | 2.3
E13 | Multi strand wires | Amazon | 16 | meter | 0.19 | 3

Item | Description | Material | Source | QTY | Measurement | Unit Price | Total Price
E14 | Red Push button (18mm) | | University Lab | 1 | Piece | 1 | 1
| | | | | Subtotal | | € 47.69
3D Printed Components
P01 | Encoder Wheel | PLA | University Lab | 2 | Piece | 1 | 2
P02 | GT2 15T Motor Pulley | PLA | University Lab | 2 | Piece | 1 | 2
P03 | GT2 15T idler pulley | PLA | University Lab | 2 | Piece | 1 | 2
Item | Description | Material | Source | QTY | Measurement | Unit Price | Total Price
P04 | X Axis Idler fixture | PLA | University Lab | 1 | Piece | 1 | 1
P05 | X Carriage | PLA | University Lab | 1 | Piece | 6 | 6
P06 | Y Axis Motor Fixture | PLA | University Lab | 1 | Piece | 11 | 11
P07 | Y Axis Idler fixture | PLA | University Lab | 1 | Piece | 8 | 8
P08 | Y Carriage | PLA | University Lab | 1 | Piece | 16 | 16
P09 | Base Board Cover | PLA | University Lab | 1 | Piece | 20 | 20
| | | | | Subtotal | | € 68.00
Grand total | | | | | | | € 161.28

6.2 FUTURE SCOPE

The future of pen plotters is poised for significant innovation and growth, particularly in the realm of immersive and interactive artistic experiences. One avenue for advancement lies in the adoption of higher-quality DC geared motors with finer gear ratios. This enhancement aims to achieve more precise positioning and smoother movement, ultimately contributing to improved accuracy in the plotting process. Concurrently, efforts are being directed towards refining the plotter's design to enhance reliability and efficiency, with a specific focus on reducing vibrations to elevate the overall quality of drawn output.

Looking ahead, future designs may prioritize a reduction in size and weight without compromising functionality and performance. This approach seeks to make pen plotters more compact and portable while maintaining or enhancing their capabilities.

Beyond these technical improvements, the integration of artificial intelligence (AI) and machine learning represents a promising frontier for pen plotters. By incorporating advanced algorithms, these devices could analyze and reproduce intricate artistic styles or patterns. This would empower users to generate unique and customized drawings based on their preferences or learned artistic techniques, ushering in a new era of personalized artistic expression.

Another avenue for innovation involves expanding the capabilities of pen plotters to accommodate multiple colors or various drawing mediums such as pencils or markers. This diversification opens up new possibilities for creativity and artistic exploration, allowing users to create more dynamic and visually engaging artworks.

Collaborative features represent yet another exciting prospect for the future of pen plotters. The development of functionalities that enable multiple pen plotters to collaborate on a single drawing or work synchronously on artwork could facilitate group projects, interactive installations, and even live art performances. This collaborative aspect holds the potential to transform the way artists and enthusiasts approach artistic creation, fostering a sense of community and shared creativity.

In summary, the future of pen plotters is marked by advancements in accuracy, connectivity, control systems, AI integration, and collaborative capabilities. These developments promise to deliver immersive and interactive artistic experiences, propelling pen plotters into new dimensions of creativity and expression.

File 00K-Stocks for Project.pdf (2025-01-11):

Designation | Specification | Quantity | Manufacturer | Image

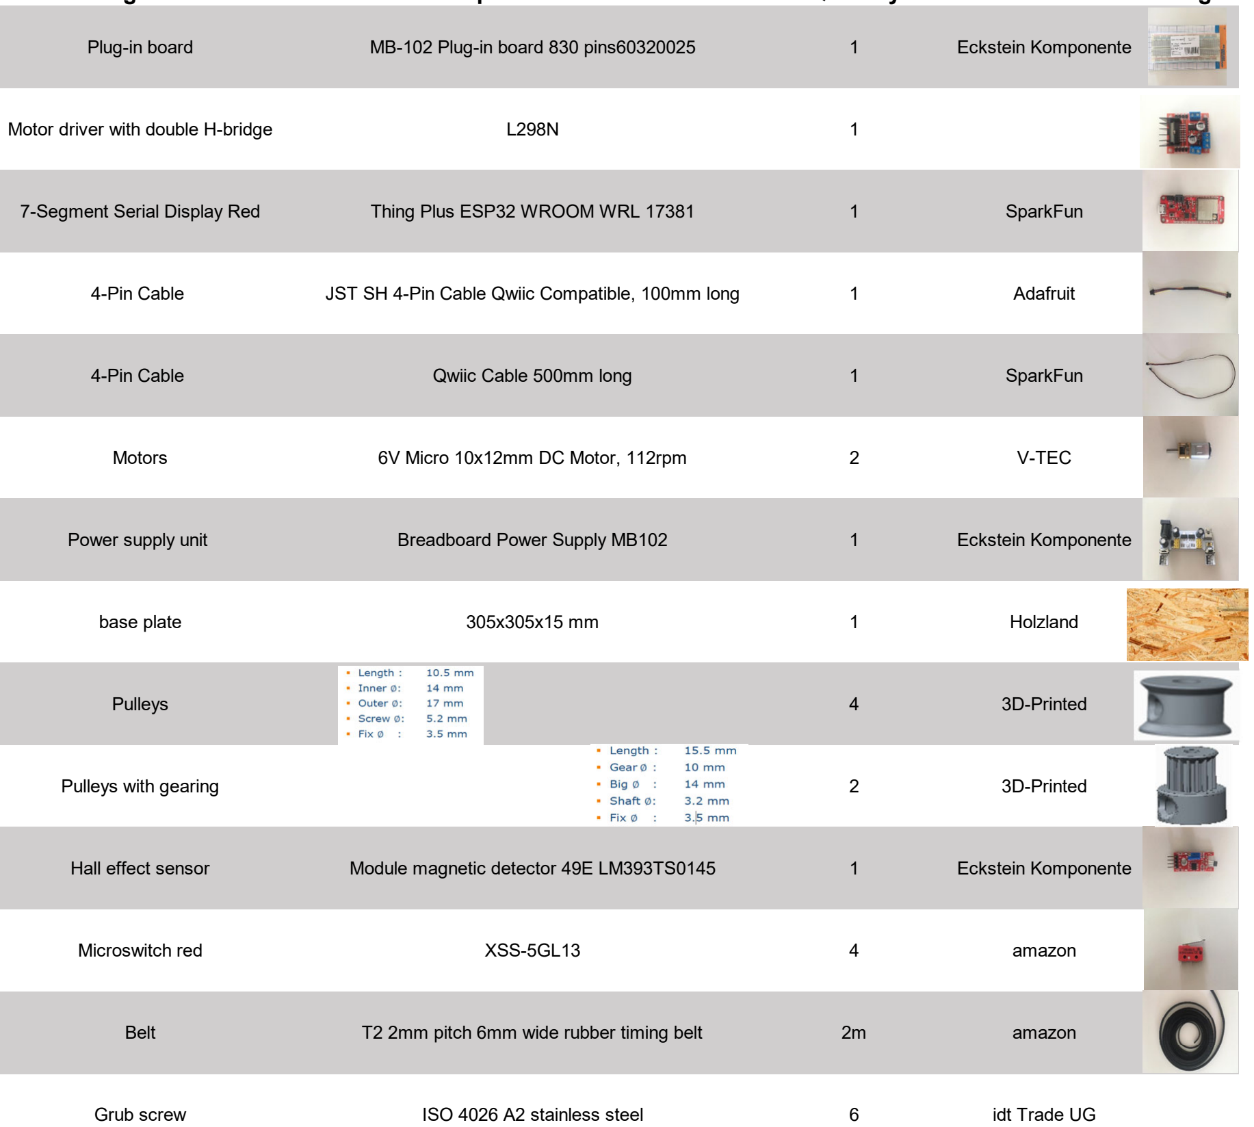
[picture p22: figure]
Plug-in board; MB-102 Plug-in board 830 pins60320025; Eckstein Komponente; Motor driver with double H-bridge; 4-Pin Cable; Qwiic Cable 500mm long; SparkFun; Power supply unit; Breadboard Power Supply MB102; base plate; Holzland; Pulleys; 3D-Printed; Pulleys with gearing; Hall effect sensor; Module magnetic detector 49E LM393TS0145; Microswitch red; XSS-5GL13; amazon; Grub screw; ISO 4026 A2 stainless steel; idt Trade UG

7-Segment Serial Display Red | Thing Plus ESP32 WROOM WRL 17381 | 1 | SparkFun
4-Pin Cable | JST SH 4-Pin Cable Qwiic Compatible, 100mm long | 1 | Adafruit
Motors | 6V Micro 10x12mm DC Motor, 112rpm | 2 | V-TEC
Belt | T2 2mm pitch 6mm wide rubber timing belt | 2m | amazon
Linear ball bearing | LMU-N6 | 8 | Misumi
Push button | 15 ∅ / length 24 [mm] | 1 | amazon
Shafts | d6 x 300mm | 4 | Misumi
Storage box | 1

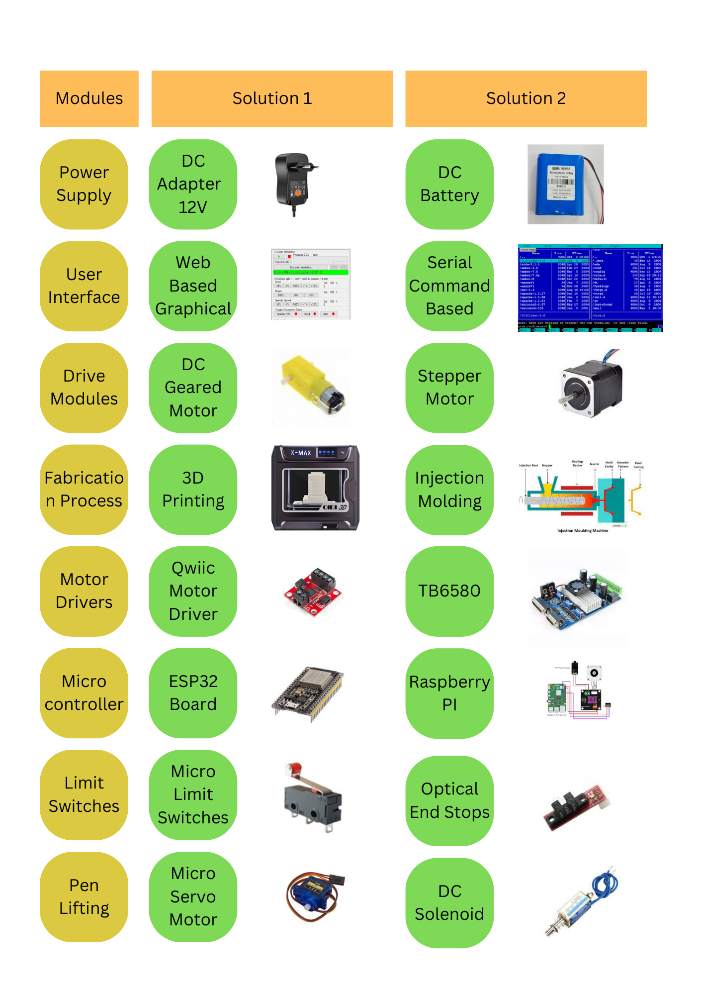
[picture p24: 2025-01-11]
00P-Morphological Chart.png

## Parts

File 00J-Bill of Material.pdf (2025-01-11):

Index of Change

Version | Description of Change | Name | Date
1.0 | Initial | Gangiredla, Varun Kumar | 25-09-2023
2.0 | Updated after finalized assembly | Choudhary Prithviraj | 02-10-2023

Table of Contents

Index of Change | Error! Bookmark not defined.
2 Bill of Material | Error! Bookmark not defined.

### 1 Subject

A computer-controlled device that utilizes pens or markers to produce precise and accurate drawings on paper is known as a pen plotter. The objective of our Workshop Mechatronics project is to create a fully operational pen plotter by employing specific components and technologies that demonstrate the seamless integration of hardware, software, and mechanical elements to achieve a specific task.

This document details the Bill of Materials (BOM) for the pen plotter developed and assembled by our team. The product's construction involves a combination of hardware, software, and mechanical components, working harmoniously to generate precise and accurate drawings on paper.

The BOM functions as a comprehensive inventory list, outlining the specific components and technologies utilized in the pen plotter's construction. It emphasizes their pivotal role in achieving the desired functionality and performance of the pen plotter.

Within this document, the presented Bill of Materials offers a thorough inventory of the key components and technologies employed in crafting the pen plotter. These carefully selected elements play a crucial role in enabling the pen plotter's precise and accurate drawing capabilities, showcasing its outstanding functionality and performance.

Bill of Material (BOM) XY-Pen Plotter XYPP_29_-BOM.docx | Doc. # | XYPP_29_BOM
| Version: | 2.0
| Date: | 03-10-2023
| page: | 1 of 5
| Project #: | XYPP_29

Validation Report XY-Pen Plotter | Doc. # | XYPP_29_-BOM
| Version: | 2.0
| Date: | 03-10-2023
| page: | 2 of 4
| Project #: | XYPP_29

### 2 Bill of Material

## Bill of Materials

Item | Description | Material | Source | QTY | Measurement | Unit Price | Total Price
Mechanical Components
M01 | Guiding Shaft 6mm | Steel | University Lab | 4 | Piece | € 3.00 | € 12.00
M02 | Timing Belt GT2 | Nylon | University Lab | 1.2 | meter | € 2.06 | € 2.47
M03 | M3 Nut | Steel | Hellweg | 20 | Piece | € 0.10 | € 1.99
M04 | M3 Bolt | Steel | Hellweg | 7 | Piece | € 0.09 | € 0.60
M05 | M4 Nut | Steel | University Lab | 5 | Piece | € 0.10 | € 0.50
M06 | M4 Bolt | Steel | University Lab | 5 | Piece | € 0.20 | € 1.00
M07 | M5 Nut | Steel | University Lab | 12 | Piece | € 0.10 | € 1.20
M08 | M5 Bolt | Steel | University Lab | 12 | Piece | € 0.20 | € 2.40
M09 | Wood screw 3.5x30 mm | Steel | Hellweg | 9 | Piece | € 0.15 | € 1.35
M10 | SS Screws M3x15mm | Steel | University Lab | 20 | Piece | € 0.06 | € 1.20
M11 | Silicon-Grease | | Amazon | 4 | gram | € 0.12 | € 0.48
M12 | Super Glue | | Amazon | 8 | gram | € 0.45 | € 3.60
M13 | 2mm Magnets | | Amazon | 60 | Piece | € 0.03 | € 1.80
M14 | 2mm Brass Rod | Brass | Hellweg | 0.5 | meter | € 2.39 | € 1.20

Item | Description | Material | Source | QTY | Measurement | Unit Price | Total Price
M19 | 6mm LMU-N6 linear bearing | | University Lab | 6 | Piece | € 1.10 | € 6.60
M20 | Tension spring 15mm | Steel | Hellweg | 2 | Piece | € 0.05 | € 0.10
Subtotal | € 45.59

Electrical Components
E01 | ESP32 Board | University Lab | 1 | Piece | € 3.20 | € 3.20
E02 | Motor Driver L298N | Amazon | 1 | Piece | € 3.00 | € 3.00
E03 | DC Motor 48:1 geared 6V | University Lab | 2 | Piece | € 4.23 | € 8.46
E04 | Limit Switch SPDT AC 250V 5A | University Lab | 4 | Piece | € 1.00 | € 4.00
E05 | Perf-Board 5x7cm | Amazon | 1 | Piece | € 2.00 | € 2.00
E06 | Screw terminals | Amazon | 6 | Piece | € 0.02 | € 0.12
E09 | Adaptor 12V (DC Power) | Amazon | 1 | Piece | € 16.91 | € 16.91
E10 | MOSFET Switch | Amazon | 1 | Piece | € 1.30 | € 1.30
E11 | 49E Hall Sensor | Amazon | 4 | Piece | € 0.60 | € 2.40
E12 | DC-DC Buck Voltage Converter | Amazon | 2 | Piece | € 1.15 | € 2.30
E13 | Multi strand wires | Amazon | 16 | meter | € 0.19 | € 3.00
E14 | Red Push button (18mm) | University Lab | 1 | Piece | € 1.00 | € 1.00
Subtotal | € 47.69

3D Printed Components
P01 | Encoder Wheel | PLA | University Lab | 2 | Piece | € 1.00 | € 2.00
P02 | GT2 15T Motor Pulley | PLA | University Lab | 2 | Piece | € 1.00 | € 2.00
P03 | GT2 15T idler pulley | PLA | University Lab | 2 | Piece | € 1.00 | € 2.00
Validation Report XY-Pen Plotter | Doc. # | XYPP_29_-BOM
| Version: | 2.0
| Date: | 03-10-2023
| page: | 3 of 4
| Project #: | XYPP_29

Item | Description | Material | Source | QTY | Measurement | Unit Price | Total Price
P04 | X Axis Idler fixture | PLA | University Lab | 1 | Piece | € 1.00 | € 1.00
P05 | X Carriage | PLA | University Lab | 1 | Piece | € 6.00 | € 6.00
P06 | Y Axis Motor Fixture | PLA | University Lab | 1 | Piece | € 11.00 | € 11.00
P07 | Y Axis Idler fixture | PLA | University Lab | 1 | Piece | € 8.00 | € 8.00
P08 | Y Carriage | PLA | University Lab | 1 | Piece | € 16.00 | € 16.00
P09 | Base Board Cover | PLA | University Lab | 1 | Piece | € 20.00 | € 20.00
Subtotal | € 68.00
Grand total | € 161.28

### 3 Conclusion

The total cost of manufacturing the pen plotter is approximately 161.28 euros, which is significantly less than the permitted cap of 200 euros and in accordance with User requirements.

– end of document –

Validation Report XY-Pen Plotter | Doc. # | XYPP_29-BOM
| Version: | 2.0
| Date: | 03-10-2023
| page: | 4 of 4
| Project #: | XYPP_29

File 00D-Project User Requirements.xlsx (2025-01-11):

Project Name |  |  | XY-Pen Plotter
Date |  |  | 2023-04-19
Version |  |  | V0 - initial
Group Name |  |  | MER0 Team # 29
Group Members |  |  | Choudhary Prithviraj, Gangiredla Varun Kumar, Khule Nitin, Pandaraboyana Dheeraj Kumar, Rao Parul Vivek Sunder
User Requirement |  |  |  |  |  |  | Technical Specification |  |  |  |  |  |  |  |  | Design Specification |  |  |  |  |  |  | Verification Protocol |  |  |  |  |  |  | Verification Report |  |  |  |  |  |  |  |  |  | Validation Protocol |  |  |  |  |  | Validation Report
UR # | module | Title | User Requirement | Remark | Domain (HW/SW/ME/all) | Must / Wish | TS # | ref. to UR # | module | Title | Technical Requirement | Remark | Domain (HW/SW/ME/all) | Must / Wish |  | DS # | ref. to TS # | module | Reference (# bill of materials, article # supplier part, ref. doc # etc..) to implementation | Description | Remark | Domain (HW, SW, ME, all) | VerP # | ref to TS # | module | test procedure (description of routine) | verification criterion | ref. # (i.e. test protocol,etc.) | Domain (HW/SW/ME/all) | VerR # | ref. to VerP # | module | test function (to be copied from verification protocol) | nominal criterion, target value | actual value | criterion passed / failed | remark | ref. # (i.e. test report, etc.) | Domain (HW/SW/ME/all) | ValP # | ref. to UR # | module | validation procedure (description of routine) | ref. # (i.e. validation protocol, customer test, etc..) | vaidation criteria | ValR # | ref. to ValP # | module | criteria passed / failed | ref. # (i.e. test report, etc.)
Application |  |  |  |  |  |  | Application |  |  |  |  |  |  |  |  | Application |  |  |  |  |  |  | Application |  |  |  |  |  |  | Application |  |  |  |  |  |  |  |  |  | Application
UR1 | Application | Intended Use | The XY-pen plotter is designed to draw a Nikolaus' house after programming and can be used within the laboratory of University by students taking part in Master course MeRo for educational reasons. |  |  |  | TS5 | UR1 | application | intended use | The XY-pen plotter is designed to draw a Nikolaus' house after programming and can be used within the laboratory of University by students taking part in Master course MeRo for educational reasons.
UR2 | Application | Use Case | The plotter has to draw a Nikolaus' house |  |  |  | TS5 | UR2 | application | use case | The Nikolaus house to be drawn should dimensions of 100 x 100 mm² maximum. |  | all | m
UR3 | Application | Application Site | Indoor purposes with portability |  |  |  | TS6 | UR2 | application | use case | The Nikolaus house to be drawn should dimensions of 150 x 150 mm² maximum. |  | all | w
UR4 | Application | Focus Group | All the people who are above age 18 can use the Pen Plotter with basic understanding of the working of Pen Plotter. |  |  |  | TS7 | UR2 | application | use case | The Nikolaus house to be drawn should adjustable in dimensions from 100 x 100 to 150 x 150 mm² maximum in 10 mm steps. |  | all | w
General Functions |  |  |  |  |  |  | General Functions |  |  |  |  |  |  |  |  | General Functions |  |  |  |  |  |  | General Functions |  |  |  |  |  |  | General Functions
UR5 | Genaral | Portability | XY pen plotter shall be carried by user of focus group. | weight up to 3kg. | all | m | TS3 | UR4 | general | portability | The pen plotter shall not be heavier than 3 kg (w/o Laptop) |  | all | m
 |  |  |  |  |  |  | TS4 | UR4 | general | portability | The pen plotter has to be carried by single user fo focus group for 5 min w/o fatigue
 |  |  |  |  |  |  | TS1 | UR3 | general | dimensions | Designing should be taken care to fit the dimensions 56*39*42 cm³ | 45 l, model Samla (IKEA) | ME | m
UR6 | Genaral | Compatibility | A pen plotter's frame must be able to work with the computer or other device that controls it. Before the plotter can be used, this can necessitate the usage of particular software or hardware components that need to be installed or configured. |  | HW/ME | M
UR7 | Genaral | User-friendliness | The plotter should be easy to use and understand, with clear instructions and controls. The software should be intuitive and allow the user to make changes easily. |  | All | W
UR8 | Genaral | Versatility | Users may need the plotter to produce a wide range of designs and patterns. Therefore, the plotter should be able to handle different types of pens, papers, and drawing media. |  | All | M
UR9 | Genaral | Service Life | The device should have a good working life time with less maintenance requirement | 1250 meters of pen life for 100 cycles | All | M
UR10 | Genaral | Speed | The plotter should be able to operate at a reasonable speed so that the user can complete their work efficiently. |  | All | M
UR11 | Genaral | Drawing capabilities | A pen plotter should be able to draw precise lines and shapes with high accuracy and consistency. It should be able to vary the thickness and color of the lines and handle different types of drawing media. |  | All | M
UR12 | Genaral | Input data handling | The plotter should be able to handle a variety of input data formats, including vector-based graphics, CAD drawings, and other image files. It should also be able to interface with different software applications and operating systems. |  | SW | M
UR13 | Genaral | Connectivity | The plotter should be able to connect to a computer or other input device via USB, Ethernet, or other interface, and receive commands and data in real-time. |  | HW | M
UR14 | Genaral | Accuracy | One of the most important requirements of a pen plotter is accuracy. The user expects the plotter to produce precise and consistent lines and shapes that match the input data. |  | All | M | Module Function base plate |  |  |  |  |  |  |  |  | Module Function base plate |  |  |  |  |  |  | Module Function base plate |  |  |  |  |  |  | Module Function - base plate
Module Function base plate |  |  |  |  |  |  | TS2 | UR3 | base plate | dimensions | basep plate has to be not bigger than 39 x 42 cm²
UR15 | Base Plate | Paper Fixation | The corners of the base plate have to be encapsulated with grippers to hold the paper in proper position. | Provide grooves to accomodate grippers | ME | M | TS8 | UR4 | base plate | paper fixation | The corners of the base plate have to be encapsulated with grippers to hold the paper in proper position w/o movementduring drawing cylce |  | HW | M
UR16 | Base Plate | Stability | It should be strong enough to sustain any vibrations and hold components o prevent movement or vibrations while charting, the base plate needs to be solid and stable. This is crucial to ensuring the plotted image is precise and of the highest caliber. |  | ME | M
UR17 | Base Plate | Size | The base plate needs to be big enough to hold the slider, other parts, and the drawing surface of the plotter. For larger or more sophisticated plotters, this might entail the use of a custom-sized base plate. |  | ME | M
UR18 | Base Plate | Material | Metal, plastic, or composite materials are just a few examples of the materials that can be used to make the foundation plate. The choice of material will be influenced by elements including cost, weight, and durability. |  | ME | M
UR19 | Base Plate | Surface Finish | To prevent distortion or uneven plotting, the base plate must to be flat and level. This is crucial for larger plotters since they could have a surface area that is more susceptible to warping or unevenness. |  | ME | M
UR20 | Base Plate | Maintenance | The base plate needs to be simple to clean and keep in good condition, as well as durable enough to withstand normal wear and tear over time. This can help to maintain the pen plotter's efficiency and smooth operation over time. |  | ME | M
UR21 | Base Plate | Leveling Feet | The base plate should have adjustable leveling feet to ensure that the plotter is level and stable during operation. This is important for ensuring accurate drawing and preventing damage to the plotter components. | Provides proper base in Un even Surfaces | ME | W
UR22 | Base Plate | Cable Management | The base plate should have provisions for cable management, such as cable ties or clips, to keep the cables organized and prevent them from interfering with the plotter's movement. |  | HW/ME | M | Module Function |  |  |  |  |  |  |  |  | Module Function |  |  |  |  |  |  | Module Function |  |  |  |  |  |  | Module Function - Hardware/Electronics
Module Function - Frame
UR23 | Frame | Size | The size of a pen plotter's frame is determined by the size of the paper or other medium that it can hold. In order to hold larger sheets of paper or other materials, larger plotters will have larger frames. |  | ME | M
UR24 | Frame | Adaptability | A pen plotter's frame must be able to work with the computer or other device that controls it. Before the plotter can be used, this can necessitate the usage of particular software or hardware components that need to be installed or configured. |  | ME | W
UR25 | Frame | Durability | A pen plotter's frame needs to be tough to endure wear and tear from frequent use. For commercial-grade plotters that might be used frequently, this is particularly crucial. |  | ME | M
UR26 | Frame | Rigidity | A pen plotter's frame needs to be rigid in order to give the plotting mechanism a firm foundation. To guarantee accuracy and precision in the output, this is crucial. |  | ME | M | Module Function |  |  |  |  |  |  |  |  | Module Function |  |  |  |  |  |  | Module Function |  |  |  |  |  |  | Module Function - Software
Module Function - pen holder
UR27 | Pen Holder | Stability | The pen must be held securely and steadily to prevent it from swaying or shifting while you're scheming. For the plotted image to be precise and of excellent quality, this is crucial. |  | ME | M
UR28 | Pen Holder | Pen Gripper | Gripper must be adjustable in order to accept various pens or writing utensils of various sizes and sorts. This can entail the use of replaceable tips or other parts that can be changed out as necessary. | To accomodate with different shapes of pens | ME | M
UR29 | Pen Holder | Pressure Control | Controlling the pressure applied to the pen or writing tool may be possible thanks to mechanics included within the pen holder. Even if the pen is used on several types of material, this can assist guarantee that the plotted image is of a consistent quality. | For equipment Safety | HW/ME | W
UR30 | Pen Holder | Maintenance | The pen holder should be simple to install, remove, clean, and maintain. This could make sure the pen plotter keeps functioning smoothly and effectively throughout time. |  | ME | M | Module Function |  |  |  |  |  |  |  |  | Module Function |  |  |  |  |  |  | Module Function |  |  |  |  |  |  | Module Function - Software
Module Function - Motor
UR31 | Motor | Motor | The motor should operate smoothly and without jerks. |  | HW | M
UR32 | Motor | Motor Types | The motor controller should be compatible with the type of motors used in the plotter. | Servo motors in our case | HW | W
UR33 | Motor | Motor Control Algorithm | The motor controller uses a control algorithm to translate the commands from the plotter control software into motor movements. The control algorithm can be open-loop or closed-loop. Open-loop control uses predetermined commands to control the motor movement, while closed-loop control uses feedback from the motor to adjust the movement in real-time. |  | HW/SW | M
UR34 | Motor | Pulse Width Modulation (PWM) | The motor controller uses PWM to control the speed of the motors. PWM is a technique that uses a series of pulses to control the average voltage applied to the motor, which in turn controls the speed. |  | HW/SW | M
UR35 | Motor | Current Sensing | The motor controller may include current sensing features to monitor the current drawn by the motors. This can help to prevent overheating and damage to the motors. |  | HW | M
UR36 | Motor | Microcontroller | The motor controller typically includes a microcontroller that processes the commands from the plotter control software and generates the signals that control the motors. |  | HW | M
UR37 | Motor | Drive System | It should be an open loop drive system with a range of available drive speeds. |  | HW/ME | M | Module Function |  |  |  |  |  |  |  |  | Module Function |  |  |  |  |  |  | Module Function |  |  |  |  |  |  | Module Function - Software
Module Function - Slider
UR38 | Slider | Movement | To prevent jerky or uneven lines in the plotted image, the slider must move smoothly and evenly. This is crucial to accomplish in order to guarantee the image's excellent quality and aesthetic attractiveness. |  | ME | M
UR39 | Slider | Precision | The slider must have a high degree of accuracy and precision when moving the plotting mechanism. This is crucial to accomplish in order to guarantee the plotted image's excellent quality and consistency. |  | HW/ME | M
UR40 | Slider | Speed | The plotting mechanism needs to be moved by the slider fast and effectively, especially when making huge or intricate images. This can reduce the amount of time needed to finish the charting procedure |  | All | M
UR41 | Slider | Compatibility | The slider must be suitable with both the type of material being used and the size and form of the plotter's drawing surface. For various plotter sizes or types, this can need the usage of several slider types. |  | ME | M
UR42 | Slider | Area Range | The Slider movements should be able to cover the whole Drawing area without any restrictions |  | ME | M
UR43 | Slider | Durability | The slider must be strong enough to endure the wear and tear that comes with repeated use over time. This can entail utilizing premium materials and parts that are made to withstand wear and tear. |  | ME | M
UR44 | Slider | Control | To precisely regulate the movement of the plotting mechanism, the slider may be managed by software or other electronic components. By doing this, it may be possible to guarantee the high level of consistency and quality of the plotted image. |  | All | M
UR45 | Slider | Working | It must be able to move at any angle for efficient outputs. |  | All | M
Module Function - Wiring |  |  |  |  |  |  | Module Function |  |  |  |  |  |  |  |  | Module Function |  |  |  |  |  |  | Module Function |  |  |  |  |  |  | Module Function - Software
UR46 | Wiring | Wire | Wiring should be finished with appropriate conductive wires. |  | HW | M
UR47 | Wiring | Wire arrangements | It must be appropriately coordinated, with no free loose ends while running. |  | HW/ME | M
UR48 | Wiring | Customizability | The user may require the pen plotter to be customizable, allowing for different types of wiring to be used or for different settings to be adjusted. |  | HW/ME | W
UR49 | Wiring | Customizability | The user may require the pen plotter to be customizable, allowing for different types of wiring to be used or for different settings to be adjusted. |  | HW | W
UR50 | Wiring | Limit switches | The plotter may require limit switches to prevent the motors from moving beyond their range of motion. The limit switches should be wired to the microcontroller and positioned appropriately. | Safety precaution | HW | M
UR51 | Wiring | Automatic tool changer | If the plotter has an automatic tool changer, it may require additional wiring and components to control the tool changing mechanism. | Optional | ME | W
UR52 | Wiring | Connection | It should be properly organized, with no loose connections while running. And also most should most efficient way of wiring for efficient mode. |  | HW/ME | M
Module Function - Power Supply |  |  |  |  |  |  | Module Function |  |  |  |  |  |  |  |  | Module Function |  |  |  |  |  |  | Module Function |  |  |  |  |  |  | Module Function - Software
UR53 | Power Supply | Input Voltage | The input voltage of the power supply should match the voltage of the local power supply. For example, in the US, the input voltage is typically 110V, while in Europe, it is 220V. |  | HW | M
UR54 | Power Supply | Output Voltage | The output voltage of the power supply should match the voltage required by the plotter's components. Typically, pen plotters require DC voltages of 12V, 24V, or 48V. |  | HW | M
UR55 | Power Supply | Protection Features | The power supply should have protection features that prevent damage to the plotter in case of power surges, short circuits, or other electrical problems. These features may include fuses, overvoltage protection, and overcurrent protection. | For equipment and human safety | HW/ME | M
UR56 | Power Supply | Current Rating | The power supply should have a current rating that is sufficient to power all of the plotter's components. The current rating is measured in amperes (A). |  | HW | M
UR57 | Power Supply | Compatibility | The power supply should be compatible with the plotter's electrical system and designed to work with the plotter's voltage and current requirements. |  | HW | M
UR58 | Power Supply | Efficiency | The power supply should be efficient and minimize power losses. This can help to reduce heat generation and extend the lifespan of the power supply. | Economical Operation | HW | M
Module Function - Coding and Control |  |  |  |  |  |  | Module Function |  |  |  |  |  |  |  |  | Module Function |  |  |  |  |  |  | Module Function |  |  |  |  |  |  | Module Function - Software
UR59 | Coding and Control | Design Creation | The first step in using a pen plotter is to create a design using a software application such as AutoCAD, Illustrator, or Inkscape. | The design can be created using vector graphics or other drawing tools. | SW | M
UR60 | Coding and Control | File Conversion | Once the design is created, it needs to be converted into a format that the plotter can understand. This is typically done using a software application that converts the design into a series of commands that the plotter can execute. |  | SW | M
UR61 | Coding and Control | Plotter Control | The plotter is controlled using a software application that sends the commands to the plotter via a USB or Ethernet connection. | The software application typically allows the user to control the speed, direction, and other parameters of the plotter's movements. | HW/SW | M
UR62 | Coding and Control | Pen Control | The pen is controlled using a mechanism that allows it to move up and down. This is typically done using a motor or solenoid that moves the pen holder up and down as commanded by the plotter control software. |  | All | M
UR63 | Coding and Control | Paper Control | The paper is controlled using a mechanism that feeds it through the plotter. | This is typically done using a series of rollers or gears that move the paper forward or backward as commanded by the plotter control software. | All | M
Module Function - Actuation |  |  |  |  |  |  | Module Function |  |  |  |  |  |  |  |  | Module Function |  |  |  |  |  |  | Module Function |  |  |  |  |  |  | Module Function - Software
UR64 | Actuation | Precision | The drive and belt actuators need to be very accurate and precise while moving the plotting mechanism. This is crucial to accomplish in order to guarantee the plotted image's excellent quality and consistency. |  | HW/SW | M
UR65 | Actuation | Speed | The plotting mechanism needs to be moved fast and effectively, especially when producing huge or intricate images. | This can reduce the amount of time needed | HW/SW | M
UR66 | Actuation | Smoothness | To prevent jerky or uneven lines in the plotted image, the drive and belt actuators must operate smoothly and uniformly. This is crucial to accomplish in order to guarantee the image's excellent quality and aesthetic attractiveness. |  | All | M
UR67 | Actuation | Durability | The drive and belt actuator setup need to be strong enough to endure the wear and tear that comes with prolonged, frequent operation. | This can entail the use of premium components and materials made to withstand wear and tear. | HW/ME | M
UR68 | Actuation | Compactibility | The size, shape, and media type of the plotter's drawing surface, as well as the drive and belt actuators, all need to be compatible. For various sizes or types of plotters, this can include the usage of various actuator types. |  | HW/ME | W
UR69 | Actuation | Control | To precisely regulate the movement of the plotting mechanism, the drive and belt actuators may be managed by software or other electrical components. By doing this, it may be possible to guarantee the high level of consistency and quality of the plotted image. |  | All | M
UR70 | Actuation | Control of tension | The drive and belt actuators may feature systems for adjusting the tension in the belts. | This can help to ensure that the plotted image is precise and of high quality even when the pen is used on various types of medium. | HW/ME | M
Module Function |  |  |  |  |  |  | Module Function |  |  |  |  |  |  |  | Module Function
UR71 | Module | Mounting board | Should have appropriate size |  | ME | M
UR72 | Module | PCB requirment | For wide range of application a suitable board must be used |  | HW | M
UR73 | Module | Operating System | Should be compatible with wide range of operating systems |  | SW | M
UR74 | Module | Software | User friendly interface |  | SW | M
UR75 | Module | User guide | Should be able to provide proper guidance to the user |  | All | M
UR76 | Module | Conformity to Standards | Device has to be designed according corresponding standards, i.e. for safety, validity of the product |  | All | M
UR77 | Module | Electronic Component Standards | All electronic components must have a adequate rated fuse in case of short circuit. |  | HW | M
UR78 | Module | Electrical Standards | All wires must be properly insulated. |  | HW | M
Non-functional Requirements
UR79 | Non Functional | Performance | The plotter should be able to perform its functions efficiently, without delays or lagging. It should be able to handle large data sets and produce high-quality output quickly. |  | HW/SW | M
UR80 | Non Functional | Usability | The plotter should be easy to use and operate. The user interface should be intuitive and easy to navigate, with clear instructions and feedback. |  | All | W
UR81 | Non Functional | Reliability | The plotter should be reliable and dependable, able to operate consistently without errors or malfunctions. It should have a long lifespan and be able to withstand regular use. |  | All | W
UR82 | Non Functional | Maintainability | The plotter should be easy to maintain and repair. It should have accessible components and spare parts that are readily available. |  | HW/ME | M
UR83 | Non Functional | Security | The plotter should be secure and protect the user's data and intellectual property. It should have safeguards against hacking, viruses, and other security threats. |  | All | M
UR84 | Non Functional | Compatibility | The plotter should be compatible with a wide range of software applications and operating systems, allowing the user to work with different tools and platforms. |  | All | M
UR85 | Non Functional | Scalability | The plotter should be scalable, able to handle larger and more complex designs as the user's needs grow. |  | All | M
UR86 | Non Functional | Portability | The plotter should be portable and easy to transport, allowing the user to work from different locations. |  | HW/ME | M
Regulatory and Standards |  |  |  |  |  |  | Regulatory and Standards |  |  |  |  |  |  |  |  | Regulatory and Standards |  |  |  |  |  |  | Regulatory and Standards |  |  |  |  |  |  | Regulatory and Standards
UR87 | Regulatory & Standards | conformity to standards | device has to be designed according corresponding standards, i.e. for safety, valid for the product |  | All | M
UR88 | Regulatory & Standards | Electrical Safety | The plotter should comply with electrical safety standards and regulations for the country or region where it is used. This may include compliance with standards for grounding, insulation, and protection against electric shock. |  | HW | M
UR89 | Regulatory & Standards | Electromagnetic Compatibility (EMC) | The plotter should comply with EMC standards and regulations to ensure that it does not interfere with other electronic devices and is not affected by electromagnetic interference. |  | HW/ME | M
UR90 | Regulatory & Standards | Emissions and Environmental Regulations | The plotter should comply with emissions and environmental regulations, including those related to noise, energy consumption, and hazardous materials. |  | HW/ME | M
UR91 | Regulatory & Standards | Product Labeling and Documentation | The plotter should have appropriate labeling and documentation, including a user manual, warning labels, and compliance certificates. |  | All | W
UR92 | Regulatory & Standards | Product Safety Standards | The plotter should comply with product safety standards, including those related to mechanical hazards, fire safety, and other risks associated with the use of the device. |  | HW/ME | M
UR93 | Regulatory & Standards | Data Protection and Privacy Regulations | The plotter may need to comply with data protection and privacy regulations if it collects or processes personal data, such as user profiles or design data. |  | SW | M
Market Requirements
UR94 | Market | Cost and Value | Pen plotters should be priced competitively, offering good value for the price. The market requires a pen plotter that provides good performance, reliability, and features at a reasonable cost. | Economical | All | W
UR95 | Market | Connectivity and Compatibility | The market requires a pen plotter that can easily connect to other devices and software platforms, such as computers or design software. Compatibility with popular software platforms and operating systems is a critical market requirement. |  | All | M
UR96 | Market | Ease of Use | Pen plotters should be user-friendly and easy to operate, even for users with limited technical knowledge. The market requires a pen plotter that is easy to set up and use, with intuitive software and user interfaces. |  | HW/SW | M
UR97 | Market | Accuracy and Precision | Pen plotters are often used for technical or artistic applications that require precise and accurate line drawing. Therefore, accuracy and precision are critical market requirements. This means that the pen plotter should be able to draw lines of consistent thickness and accuracy, without any noticeable wobble or inaccuracy in the line. |  | All | M
UR98 | Market | Durability and Reliability | Pen plotters should be designed to withstand heavy use over time without breaking down. The market requires a pen plotter that is reliable, durable, and capable of handling large, complex drawings without overheating, jamming, or breaking down. |  | All | M
UR99 | Market | Speed and Efficiency | The market requires a pen plotter that is fast and efficient at completing complex drawings. Speed and efficiency are critical market requirements for applications that require the creation of large, detailed drawings, such as architectural or engineering drawings. | For customer attraction with better features | All | M

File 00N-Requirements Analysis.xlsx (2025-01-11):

User Requirement |  |  |  |  |  |  | Technical Specification |  |  |  |  |  |  |  | Design Specifications
UR # | module | Title | User Requirement | Remark | Domain (HW/SW/M E/all) | Mu st / Wi sh | TS # | ref. to UR # | module |  | Title | Technical Requirement | Remark | Domain (HW/SW /ME/all) | DS # | ref. to TS # | module | Reference (# bill of materials, article # supplier part, ref. doc # etc..) to implementation | Description
Application |  |  |  |  |  |  | Application
UR1 | application | intended use | Crafted for educational purposes, the XY-pen plotter is engineered to sketch a Nikolaus' house through programming. It finds its application within the university laboratory, serving as a tool for students enrolled in the Master course MERO to enhance their learning experience. |  | all | m | TS1 | UR1 | application |  | intended use | The XY-pen plotter is specifically engineered to draw a representation of Nikolaus' house based on programmed instructions. Its intended use is within the university laboratory, catering to students enrolled in the Master course MERO for educational purposes. |  | All | Application
UR2 | application | use case | The plotter is tasked with sketching the design of Nikolaus' house. |  | all | m | TS2 | UR2 | application |  | use case | The depiction of Nikolaus' house drawn by the plotter should adhere to maximum dimensions of 100 x 100 mm².. |  | all | DS1 | TS1 |  |  | XY Plotter 'Model Mero Team 29'
UR3 | application | user environment | Designed for indoor use with a focus on portability. | Functions optimally on flat surfaces. | all | m | TS3 | UR2 | application |  | use case | The drawn representation of Nikolaus' house should adhere to maximum dimensions of 150 x 150 mm².. |  | all | DS2 | TS2, TS3 |  | Bill of Materials # BOM_T29 | The method or mechanism employed for motion in the x/y- direction within the workspace.
UR4 | application | Focus Group | Male, female, and diverse individuals within the age group of 20 to 30 years old. |  | all | m | TS4 | UR2 | application |  | use case | The drawn representation of Nikolaus' house should be adjustable in dimensions, ranging from 100 x 100 mm² to a maximum of 150 x 150 mm², with increments of 10 mm. |  | all | General Functions
General Functions |  |  |  |  |  |  |  |  |  |  |  |  |  |  | DS3 | TS4, TS5 | General | Bill of Materials # BOM_T29 | The weight of the pen plotter should not exceed 3 kg, adhering to the specified requirement.
UR5 | general | portability | The XY pen plotter is designed to be portable, allowing users from the specified focus group to easily carry it. | Weighs up to 3kg. | all | m | General Functions |  |  |  |  |  |  |  | DS4 | TS11, TS14 | General | Bill of Materials # BOM_T29 | The dimensions of the base plate are specified as 305 x 305 x 12 mm.
 |  | portability | It should be assembled and capable of transportation without the need for disassembly. |  | all | m | TS5 | UR5 |  | general |  | The weight of the pen plotter, excluding the laptop, should not exceed 3 kg. |  | all | DS5 |  | General | From CAD model | Overall dimension 305*305*300mm3
UR6 | general | dimensions | The XY pen plotter must be compact enough to fit within a box with dimensions of 56x39x42 cm. |  | all | m | TS6 | UR5 |  | general |  | The pen plotter should be designed to be carried by a single user from the focus group for up to 5 minutes without causing fatigue. |  | ME | DS6 | TS6 | General | Bill of Materials # BOM_T29 | The entire model should be designed to fit within the dimensions of a storage box measuring 56 x 39 x 42 cm³.
UR7 | general | Life Time | The XY pen plotter is expected to have a lifecycle of at least 70 million units of pen motion or be capable of completing 100 cycles of drawing Nikolaus' house. |  | all | m | TS7 | UR6 |  | general |  | The design should be meticulously crafted to ensure that the pen plotter fits within the dimensions of 56 x 39 x 42 cm³. | 45 l, model Samla (IKEA) | ME | DS7 | TS12, TS14 | General | Bill of Materials # BOM_T29 | Paper clips will be utilized to secure and fix the paper in place during the drawing process.
UR8 | general | Durability | Constructed to be sturdy and robust, the XY pen plotter is designed to withstand external vibrations and disturbances effectively. |  | all | m | TS8 | UR7, UR35 |  | general |  | The battery capacity should be sufficient to support the pen plotter through a lifetime of 100 cycles of sketching Nikolaus' house, which is approximately 120 minutes in total. |  | HW | DS8 | TS10 | General | Bill of Materials #E14 BOM_T29 | The inclusion of an emergency push button is implemented for immediate halting or interruption of the pen plotter's operation in critical situations.
UR9 | general | Emergency | The XY pen plotter is equipped with an emergency stop feature for immediate halting of operations in unforeseen situations. |  | all | m | TS9 | UR8 and UR24 |  | general |  | Materials used will be Thermoplastics and some metal components that give the structural rigidity. |  | ME | DS9 | TS9 | General | Bill of Materials # BOM_T29 | Microswitch red - XSS-5GL13
UR10 | general | Operating Time | The XY pen plotter is designed to efficiently complete the rendering of Nikolaus' house within one minute. |  | all | w | TS10 | UR9 |  | General |  | Should contain a Normally Closed (NC) Switch. |  | HW | Module Functions
Module |  |  |  |  |  |  | TS11 | UR10 |  | general |  | Pen should move in the range of 1cm/sec to 2 cm/sec. |  | SW | DS10 | TS 13 | Module | Bill of Materials # BOM_T29 | Rubber bushings are employed beneath the base plate to provide vibration dampening and support for enhanced stability during operation.
Function base plate |  |  |  |  |  |  | Module Function base plate |  |  |  |  |  |  |  | DS11 | TS15 | Module | Bill of Materials #M19 BOM_T29 | Linear ball Bearings
UR11 | base plate | paper fixation | Grippers are integrated at the corners of the base plate to securely encapsulate and hold the paper in the correct position. | Grooves are incorporat ed into the design to accommo date grippers, ensuring a secure placement and positionin g of the paper on the base plate. | HW | m | TS12 | UR11 |  | base plate |  | base plate has to be not bigger than 39 x 42 cm² |  | ME | DS12 | TS16, TS18, TS19 | Module | Bill of Materials #E03 BOM_T29 | DAGU - DG01D 48:1 - Mini Dc Gear Motor
UR12 | base plate | Securing and fixing the various parts together. | The design should allow for the accommodation of all components effectively. |  | HW | m | TS13 | UR12 |  | base plate |  | Grippers will be positioned at the corners of the base plate to encapsulate and secure the paper, preventing any movement during the drawing cycle. |  | HW | DS13 | TS17 | Module | Bill of Materials #E02 BOM_T29 | Qwiic Motor Driver
UR13 | base plate | Support | Incorporate bushings to prevent slipping and dampen vibrations effectively. |  | HW | m | TS14 | UR13 |  | base plate |  | Use rubber bushings to provide support and damping for the base plate. |  | ME | DS14 | TS20 | Module | CAD model 3D printed | Pen Holder
UR14 | base plate | paper dimensions | Designed to accommodate standard paper sizes for versatility and convenience. |  | HW | m | TS15 | UR14 |  | base plate |  | The pen plotter is designed to accommodate standard paper size A4 and smaller, while also providing sufficient space to house all other electronic components. |  | ME | DS15 | TS21, TS22 | Module | Bill of Materials #M02 BOM_T29 | Utilizing a T2 timing belt with a 2mm pitch and a width of 6mm for specific mechanical applications in the pen plotter design.
Module |  |  |  |  |  |  | Module Function |  |  |  |  |  |  |  | DS16 | TS21, TS22 | Module | Bill of Materials #P02,P03 BOM_T29 | Pulleys
Function - Driving Unit |  |  |  |  |  |  | TS16 | UR15 , UR25 |  | Driving Unit |  | Employing high-quality bearings and shafts in the design to minimize vibrations during the movement of the pen plotter. |  | HW | DS17 | TS23 | Module | Bill of Materials #E01 BOM_T29 | Thing Plus ESP32 WAROOM WRL 17381
UR15 | Driving Unit | architecture | Incorporates robust engineering techniques to minimize vibrations and enhance stability. |  | HW | w | TS17 | UR16 |  | Driving Unit |  | Use brushless 5V DC motors to drive the penholder. |  | HW | DS18 | TS24 | Module | Bill of Materials # BOM_T29 | Zip tags and Bands
UR16 | Driving Unit | movement technique | Incorporates a motorized system to drive the penholder for precision and controlled movements. |  | HW | m | TS18 | UR17 |  | Driving Unit |  | Use of a motor controller to change the voltage and thereby change the velocity of the motor. |  | HW | DS19 | TS25 | Module | Bill of Materials # BOM_T29 | Cables
UR17 | Driving Unit | variability | Designed to effectively handle a range of velocities for versatile and adaptable performance. |  | all | w | TS19 | UR18 |  | Driving Unit |  | A gear motor is to be used. |  | HW | DS20 | TS27 | Module | Bill of Materials # BOM_T29 | The MB-102 plug- in board has 830 pins arranged in a 600-point terminal strip and a 320- point distribution strip, providing a total of 25 tie- points per row.
UR18 | Driving Unit | It can accommodate a variety of choices or preferences. | Avoiding the use of a stepper motor in the design. |  | HW | m | TS20 | UR19 |  | Driving Unit |  | By using 2 motors and syncing their speed depending on the angle required. |  | ME | DS21 | TS28 | Module | Bill of Materials # BOM_T29 | The Breadboard Power Supply TS1171 is a specific power supply unit designed for use with breadboards, providing a convenient and regulated power source for electronic circuits during prototyping and experimentation.
UR19 | Driving Unit | Providing flexibility in drawing capabilities. | Capable of drawing lines at various angles within a 2D plane, showcasing versatile design and functionality. |  | all | m | Module Function |  |  |  |  |  |  |  | DS22 | TS7, TS29, TS30, TS 31 | Module | Bill of Materials # BOM_T29 | A lithium-ion battery is a type of rechargeable battery commonly used in various electronic devices, ranging from mobile phones to electric vehicles. It is known for its high energy density and lightweight design, making it a popular choice for portable applications.
Module |  |  |  |  |  |  |  |  |  |  |  |  |  | HW | DS23 | TS26 | Module | Bill of Materials # BOM_T12 | Limit Switches - Module magnetic detector 49E
Function - pen holder |  |  |  |  |  |  | TS21 | UR20 thru UR22 |  | Pen Holder |  | The penholder must have a screw clamp to firmly hold the pen and accommodate various types of pens. |  |  | DS24 | TS22,TS2 3,TS32,T S34 | Module | ISO 9001, ISO14001 | International Organization for Standardization (ISO)
UR20 | pen holder | Pen Gripping | Designed to securely grip a pen, ensuring a firm hold without slipping during operation. |  | HW | m |  |  |  |  |  |  |  |  | DS25 | TS33 | Module |  | International Electro technical Commission (IEC) Standard
UR21 | pen holder | Incorporating a flexible gripping mechanism to enhance adaptability and versatility in holding various tools or instruments. | Featuring an adjustable gripper to securely hold various sizes of objects, accommodating diameters of up to 15mm. |  | HW | m | Module Function |  |  |  |  |  |  |  | DS26 | TS 34 | Module | ISO 3740 and ISO 3744 | ISO Standards for noise emissions
UR22 | pen holder | Service and repair | Pen replacement with ease. |  | HW | w | TS22 | UR23 |  | Movement Mechanism |  | Standard parts should be used like pulleys and belts. |  | HW | DS27 | TS 35 | Module | CAD model 3D printed | Swapping techniques included in designing of grippers and joints
Module |  |  |  |  |  |  | TS23 | UR26,UR27 |  | Movement Mechanism |  | The design incorporates the mounting of pulleys to the motor shaft and utilizes belts to convert the rotary motion of the motor into linear motion for precise movement in the pen plotter. |  | ME |  | TS 36
Function - Movement Mechanism |  |  |  |  |  |  | Module Function
UR23 | Movement Mechanism | standardization of parts | Standard parts should be used like pulleys and belts |  | HW | m | TS24 | UR28 |  | Circuitry |  | Standard ESP32 controller should be used. |  | HW
UR24 | Movement Mechanism | Ensuring the sustainability and durability of the structure over time. | The support structures are designed to be lightweight for enhanced portability and ease of handling. |  | HW | w | TS25 | UR29 |  | Circuitry |  | Using zip tags and bands to make the wiring tangle free. |  | HW
UR25 | Movement Mechanism | Incorporating low traction elements to reduce resistance and enhance ease of movement. | Minimizing frictional contact points to reduce wear and ensure smooth operation over time. |  | HW | w | TS26 | UR30 |  | Circuitry |  | Implementing color codes for standard wiring, such as using red for positive connections and black for ground connections, to enhance clarity and facilitate easy identification. |  | HW
UR26 | Movement Mechanism | energy conversion | Utilizing a mechanism for converting rotary motion into linear motion. |  | HW | m | TS27 | UR31 |  | Circuitry |  | Use Normally closed type of limit switches |  | HW
UR27 | Movement Mechanism | The locus of pen motion refers to the path or trajectory followed by the pen during its movement. | The pen is capable of moving in both directions along a linear path. |  | HW | m | TS28 | UR32 |  | Circuitry |  | Use a full solder less breadboard for connecting the entire electronic system. |  | HW
Module Function - Circuitry |  |  |  |  |  |  | Module Function
UR28 | Circuitry | Controller type | Utilizing a standard ESP32 controller for the operation and control of the system.. |  | HW | m | TS29 | UR34 |  | Supply Unit |  | 9V DC power supply |  | HW
UR29 | Circuitry | Wiring | Ensuring tangle-free wiring to facilitate easy troubleshooting and maintenance. |  | all | m | T30 | UR36, UR37, UR39 |  | Supply Unit |  | Rechargeable Li-ion Battery should be used |  | HW
UR30 | Circuitry | Wiring protocol | Implementing standard wiring protocols to ensure compatibility and ease of integration. |  | HW | m | T31 | UR38 |  | Supply Unit |  | Positioning the battery unit at a corner of the base plate to ensure convenient and easy accessibility for maintenance or replacement. |  | HW&ME
UR31 | Circuitry | Ensuring safety in connections to prevent any risks or hazards during operation. | Incorporating limit switches to enable accurate end-to-end detection for precise control and safety. |  | HW | m | Regulatory and Standards
UR32 | Circuitry | Circuit visibility | Utilizing a breadboard for making connections, providing a flexible and prototyping-friendly approach. |  | HW | m | T32 | UR40 |  | regulatory & standards |  | Adhering to relevant standards such as ISO for mechanical components and IEC for electronic parts during the procurement process to ensure compliance and quality.
UR33 | Circuitry | Circuit safety | No open wires |  | HW | m | T33 | UR40 |  | regulatory & standards |  | Utilizing either IEC 60950 or IEC 62368 standards for electrical safety to mitigate and prevent electrical hazards in the pen plotter design.
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

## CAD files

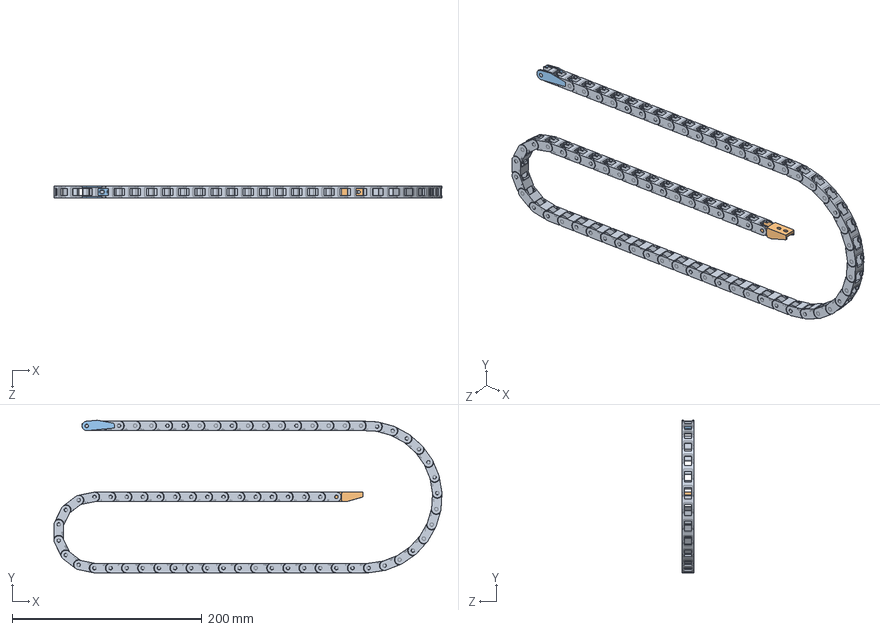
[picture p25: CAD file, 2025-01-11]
38_Cable_Chain_7x7.SLDASM
408.9 x 160.9 x 12.7 mm
main body x 70
End 1
End 2

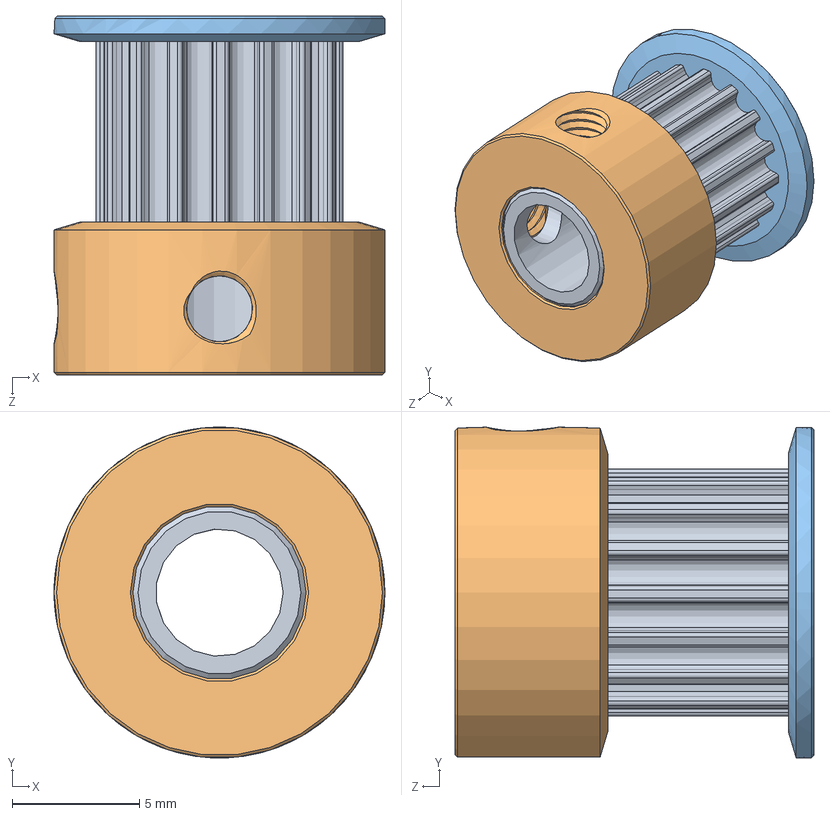
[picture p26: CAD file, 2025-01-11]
35_Pulley_16T_GT2_6mm_Assembly.SLDASM
13.0 x 13.0 x 14.1 mm
Pulley 16th GT2
Cheeck thick
Cheeck thin

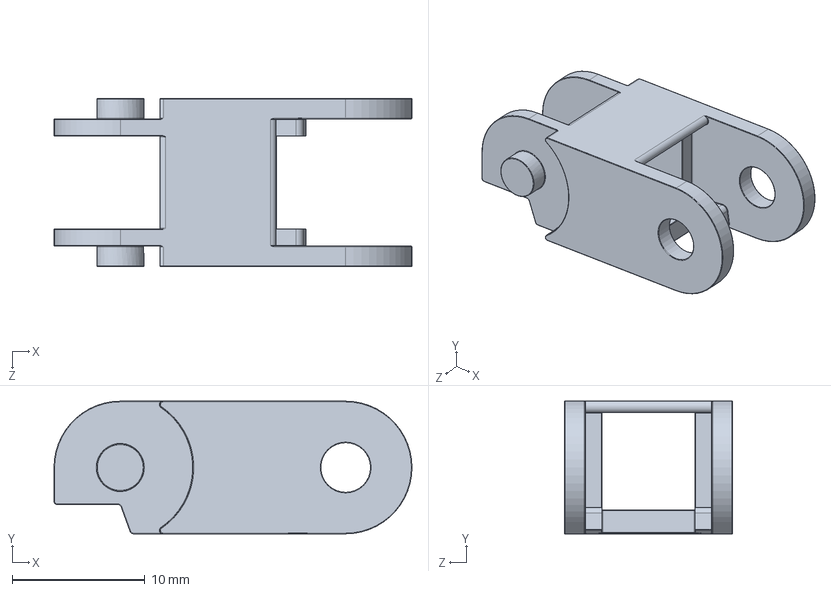
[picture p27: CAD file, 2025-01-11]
45_Main_Body.SLDPRT
27.0 x 10.0 x 12.7 mm

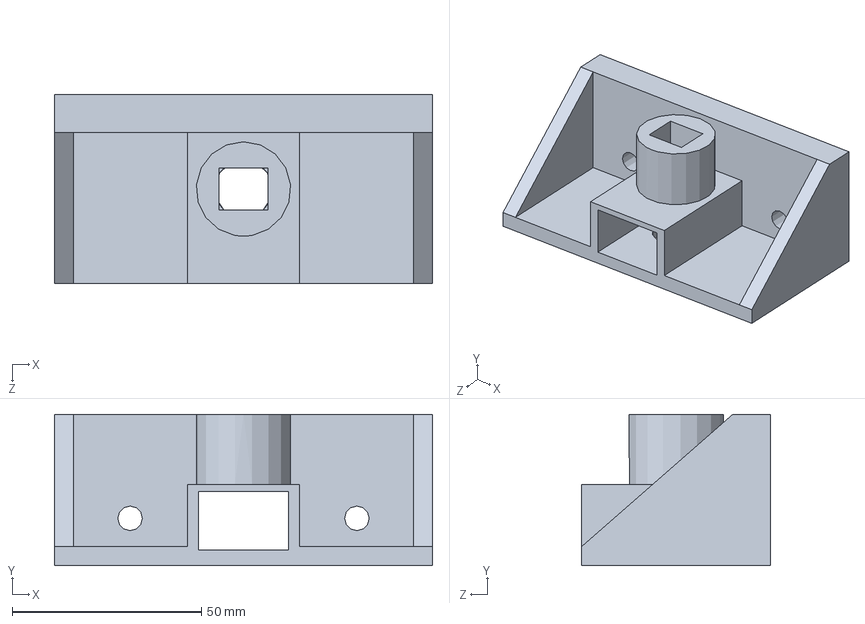
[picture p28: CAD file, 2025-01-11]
55_X1_Support.SLDPRT
100.0 x 40.0 x 50.0 mm

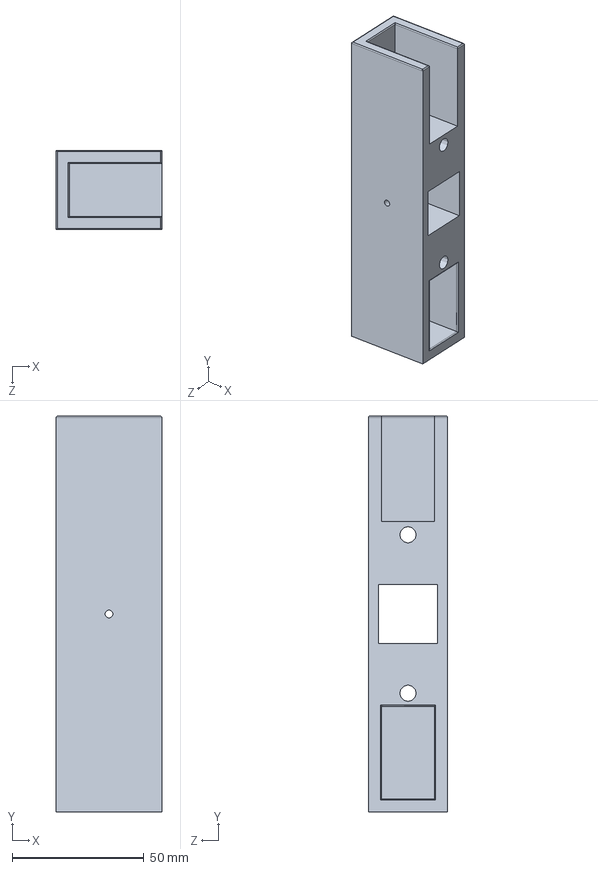
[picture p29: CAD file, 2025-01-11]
57_Y1_Support.SLDPRT
40.0 x 150.0 x 30.0 mm

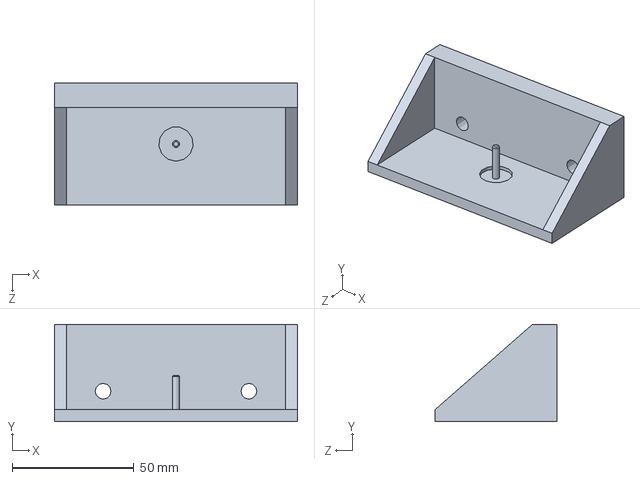
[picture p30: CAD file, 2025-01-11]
56_X2_Support.SLDPRT
100.0 x 40.0 x 50.0 mm

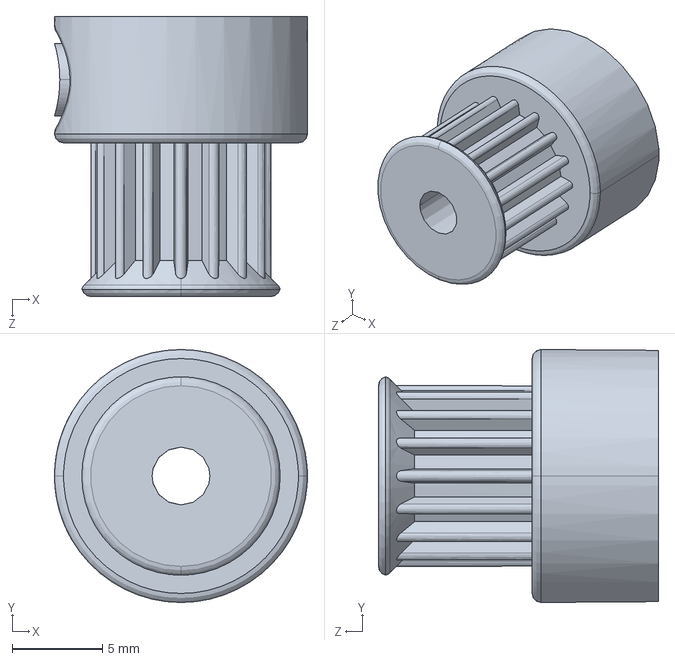
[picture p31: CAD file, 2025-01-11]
51_Gear_Pulley.SLDPRT
14.0 x 14.0 x 15.5 mm

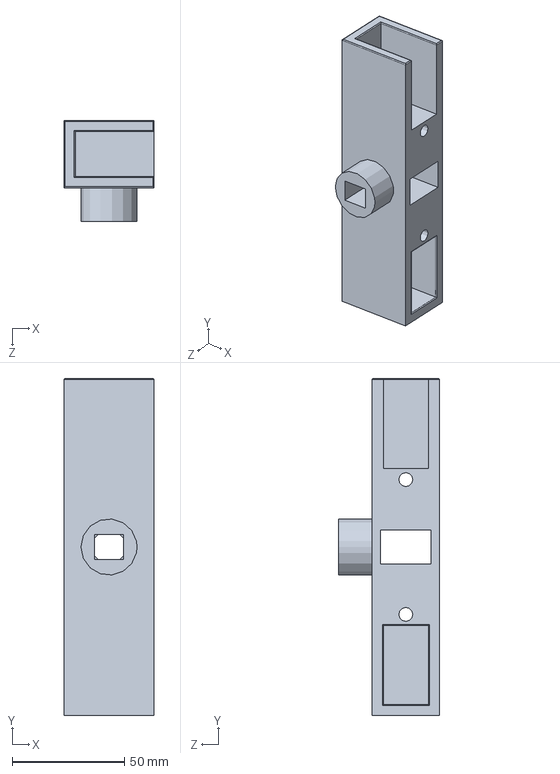
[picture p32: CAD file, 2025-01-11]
58_Y2_Support.SLDPRT
40.0 x 150.0 x 45.0 mm

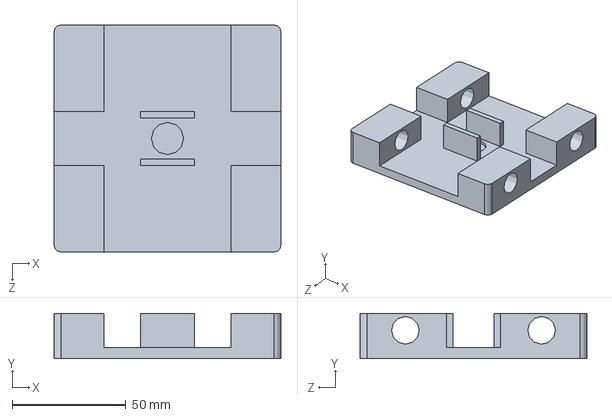
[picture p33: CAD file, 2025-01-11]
53_Paper_Holder.SLDPRT
100.0 x 20.0 x 100.0 mm

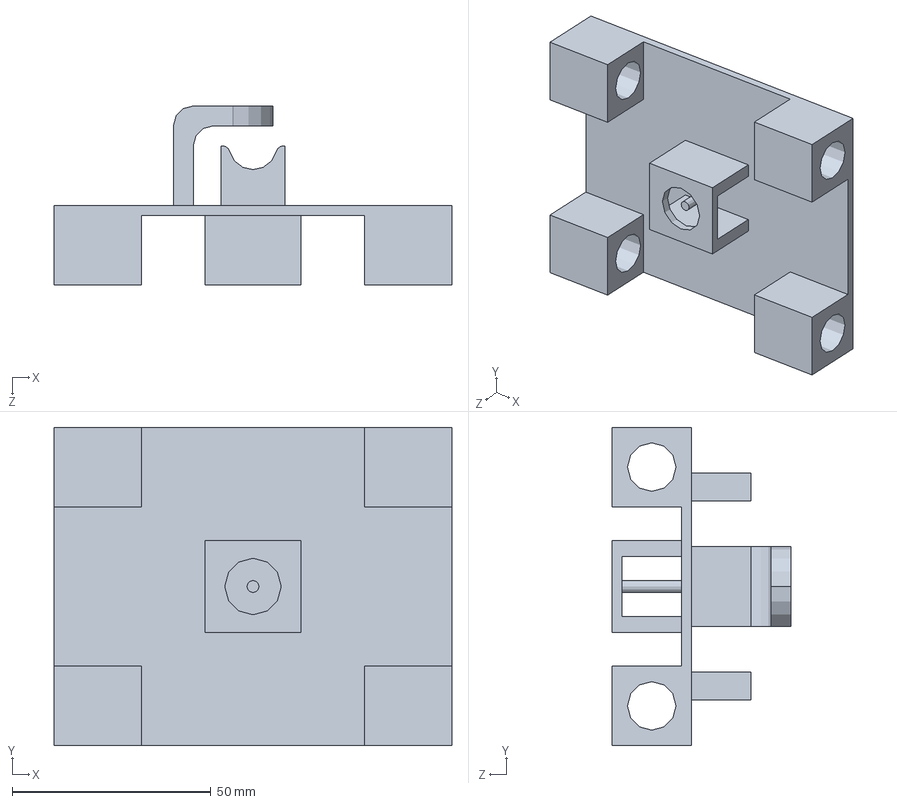
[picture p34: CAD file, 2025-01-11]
52_Gripper.SLDPRT
100.0 x 80.0 x 45.0 mm

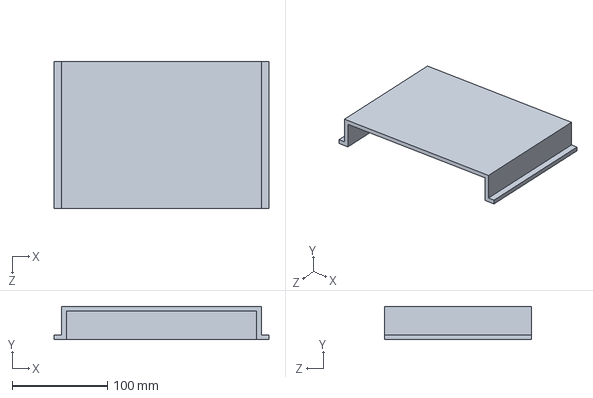
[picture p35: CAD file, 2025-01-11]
49_Storage.SLDPRT
226.0 x 35.0 x 155.0 mm

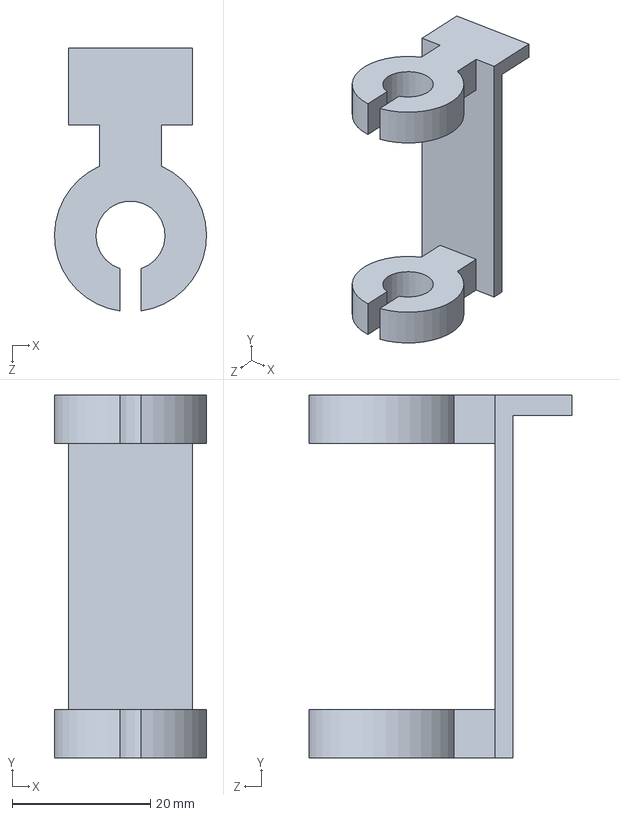
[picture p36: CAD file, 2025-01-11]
46_Pen_Holder_New.SLDPRT
22.0 x 52.5 x 38.0 mm

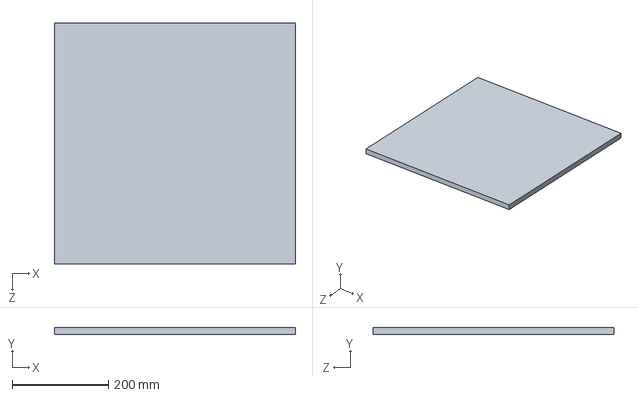
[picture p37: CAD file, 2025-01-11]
31_Base_Frame.SLDPRT
500.0 x 15.0 x 500.0 mm

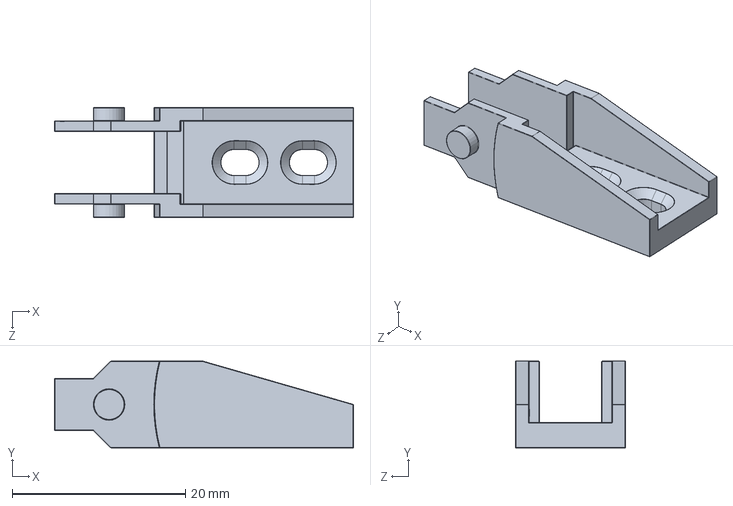
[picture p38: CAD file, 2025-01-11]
39_End_Piece_1.SLDPRT
34.5 x 10.0 x 12.7 mm

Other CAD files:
50_Cap.SLDPRT
42_End_Effector_Base_2.SLDPRT
33_A4_Paper.SLDPRT
40_End_Piece_2.SLDPRT
01_Top_Right_Plate.SLDPRT
02_Top_Left_Plate.SLDPRT
04_Stepper_Mount_Right.SLDPRT
05_Stepper_Mount_Left.SLDPRT
06_Standard_Breadboard.SLDPRT
07_SS_5GL13_Stepper.SLDPRT
09_Shaft_Connector.SLDPRT
11_PushButton_Red.SLDPRT
12_Pulley_Base.SLDPRT
13_Pulley_16T_GT2.SLDPRT
14_Pen_Holder.SLDPRT
15_Motor_Housing.SLDPRT
16_Marking_Tip.SLDPRT
17_Linear_Bearing_LMU-N6.SLDPRT
20_GT2_20T_Pulley.SLDPRT
21_GT2_20T_Motor_Mount.SLDPRT
22_Gear_Pulley_V2.SLDPRT
23_End_Effector_Base.SLDPRT
24_End_Effector_Right.SLDPRT
25_End_Effector_Left.SLDPRT
26_End_Effector_Base_Connector.SLDPRT
27_DG01D_Motor.SLDPRT
28_Bearing_Thin.SLDPRT
29_Bearing_Thick.SLDPRT
30_Bolt.SLDPRT
37_Bolt_83.SLDPRT
41_End_Effector_Base_1.SLDPRT
43_End_Effector_Top.SLDPRT
44_Foot.SLDPRT
48_Storage_Support.SLDPRT
54_Screw.SLDPRT

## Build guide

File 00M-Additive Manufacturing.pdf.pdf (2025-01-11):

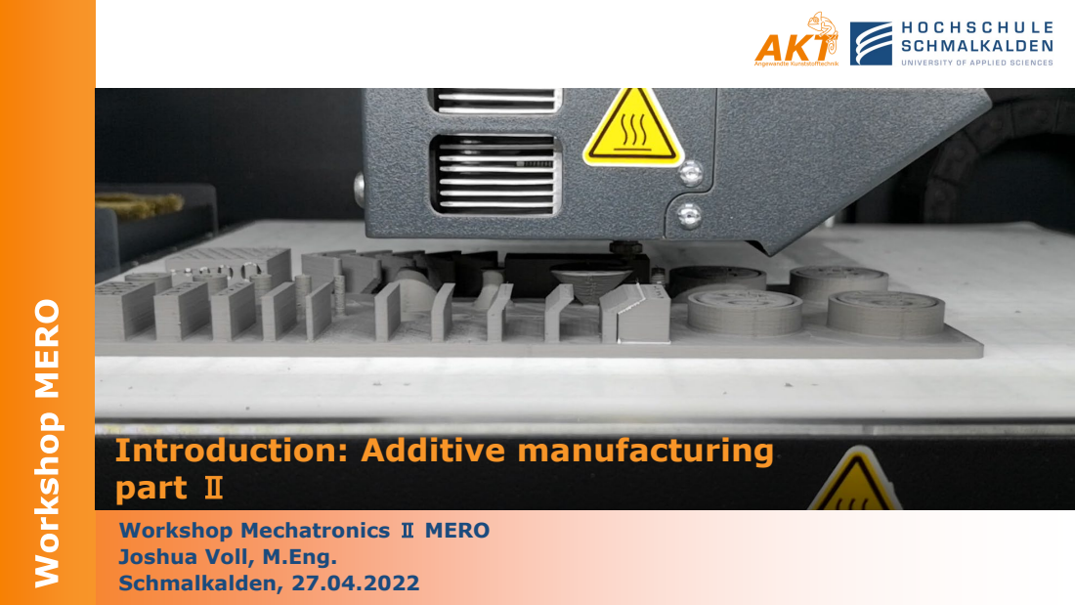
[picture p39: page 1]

Introduction: Additive manufacturing
part Ⅱ
Workshop Mechatronics Ⅱ MERO
Joshua Voll, M.Eng.
Schmalkalden, 27.04.2022

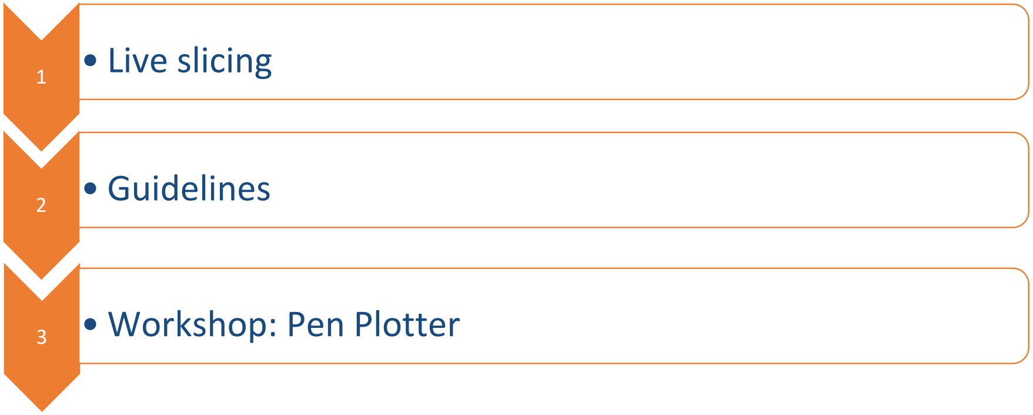
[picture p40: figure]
• Live slicing; • Guidelines; 3 • Workshop: Pen Plotter

Joshua Voll
Samuel Werner

Workshop MERO
introduction: Additive manufacturing

Folie

2

## Agenda

Folie

3

## Live-slicing

Cura

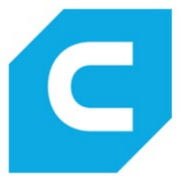
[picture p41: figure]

Folie

4

## Agenda

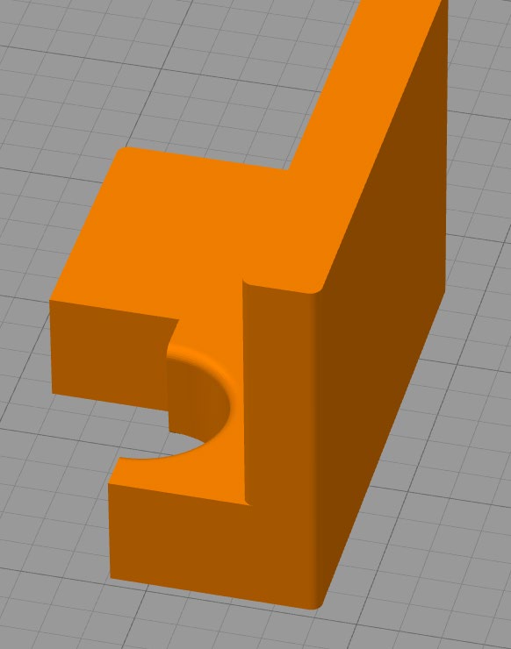
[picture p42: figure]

Folie

5

## Guidelines

What do I have to pay attention to when designing?
Important: No radii at the bottom!

Connection to build board!

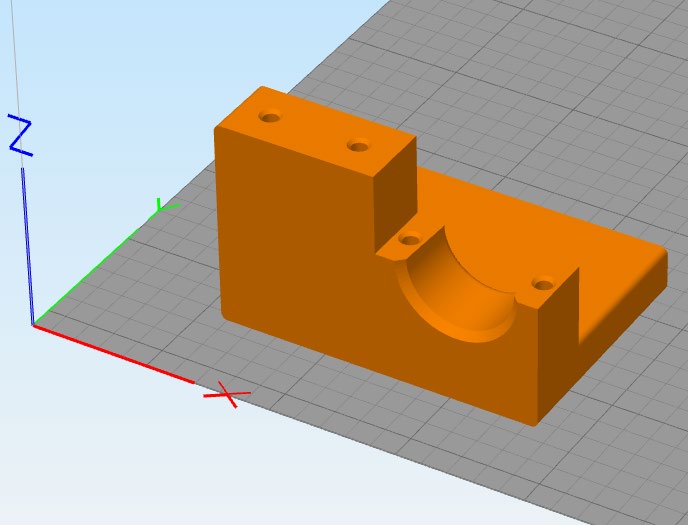
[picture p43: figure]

Folie

6

## Guidelines

What do I have to pay attention to when designing?
Important: If possible align your drill holes in Z direction!

Connection to build board!
Align your drill holes!

Folie

7

## Guidelines

What do I have to pay attention to when designing?
Important: Be aware of the anisotropic material properties! | weak

Connection to build board!
Align your drill holes!
Anisotropic material properties!

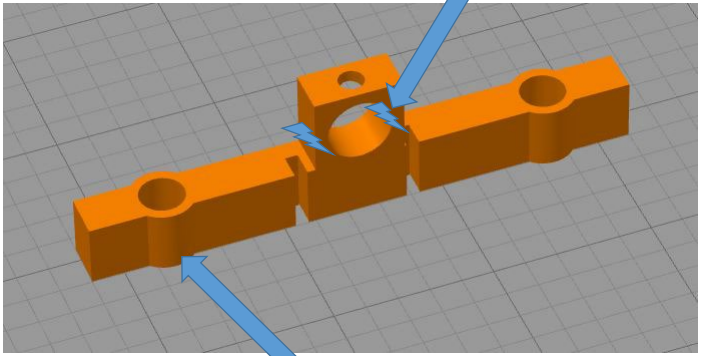
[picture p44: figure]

strong

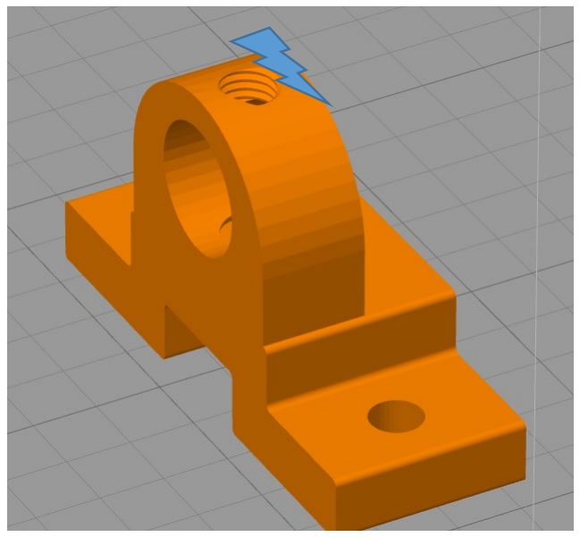
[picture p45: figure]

Folie

8

## Guidelines

What do I have to pay attention to when designing?
Important: Do not construct threads!

Connection to build board!
Align your drill holes!
Anisotropic material properties!
Cut threads after printing!

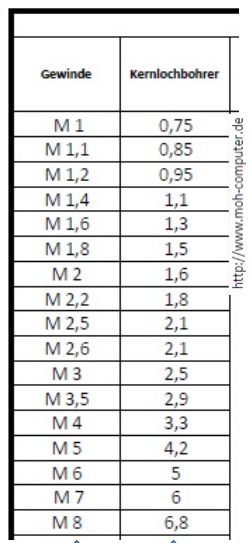
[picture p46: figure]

necessary hole diameter
required thread

Folie

9

## Guidelines

What do I have to pay attention to when designing?
Important: Holes become smaller due to the manufacturing process!

Connection to build board!
Align your drill holes!
Anisotropic material properties!
Cut threads after printing! Design holes 0.2 mm larger!

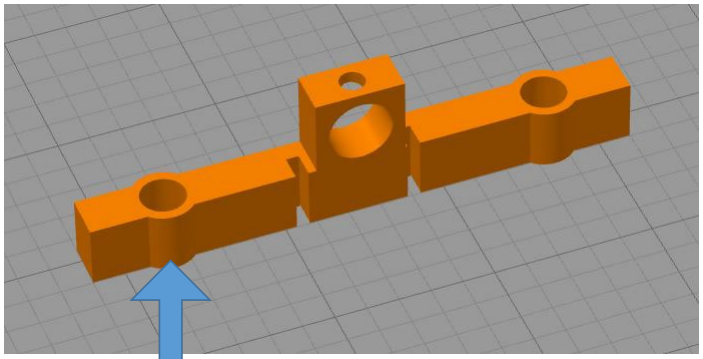
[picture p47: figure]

in CAD: 6 mm
in real: 5,8 mm

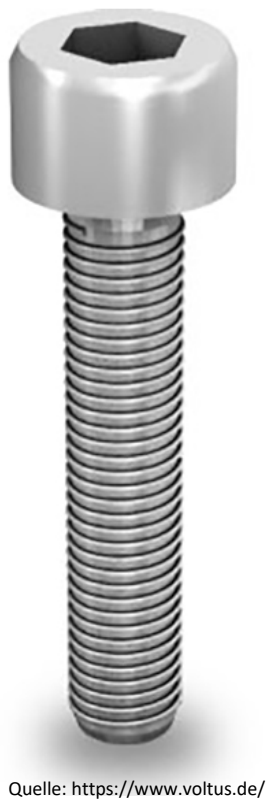
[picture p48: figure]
Quelle: https://www.voltus.de/

Folie 10

## Guidelines

What do I have to pay attention to when designing?
Important: Do not print standard parts!

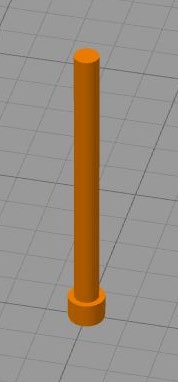
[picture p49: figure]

Connection to build board!
Align your drill holes!
Anisotropic material properties!
Cut threads after printing! Design holes 0.2 mm larger! Use standard parts!

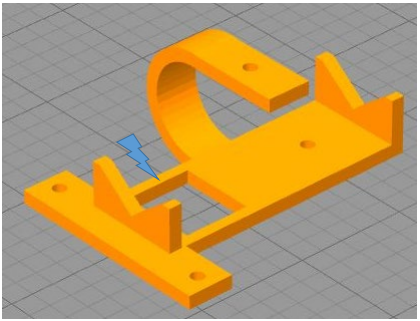
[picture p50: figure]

Folie 11

## Guidelines

What do I have to pay attention to when designing?
Important: Do not design areas that are too thin!

Connection to build board!
Align your drill holes!
Anisotropic material properties!
Cut threads after printing! Design holes 0.2 mm larger! Use standard parts!
Attention to the wall thickness!

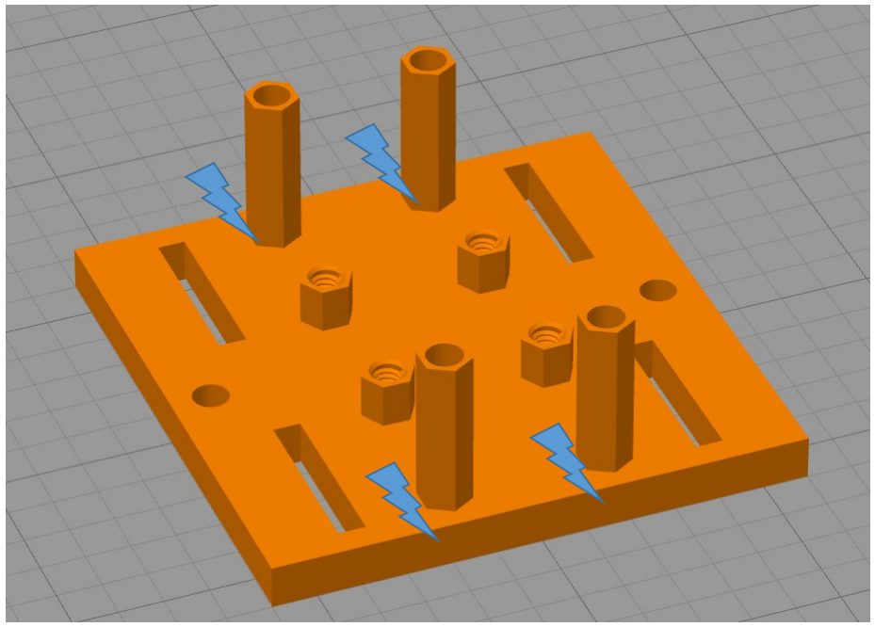
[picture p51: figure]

Folie 12

## Guidelines

What do I have to pay attention to when designing?
Important: Do not design sharp-edged transitions!

Connection to build board!
Align your drill holes!
Anisotropic material properties!
Cut threads after printing! Design holes 0.2 mm larger! Use standard parts!
Attention to the wall thickness! Round off connections!

Folie 13

## Agenda

## Building utensils

pen plotter box

Folie 14

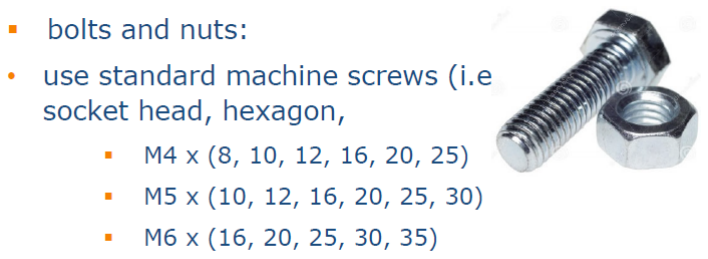
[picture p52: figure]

Joshua Voll | Workshop Mechatronics Ⅱ MERO
Designation | Specification | Quantity | Manufacturer | Image
Plug-in board | MB-102 Plug-in board 830 pins60320025 | 1 | Eckstein Komponente
Moto Driver | Qwiic Motor Driver | 1 | SparkFun
7-Segment Serial Display Red | Thing Plus ESP32 WROOM WRL 17381 | 1 | SparkFun
Cable | | 65 | Keyestudio
lithium battery + cable | | 1 | SparkFun
Motors | DAGU - DG01D 48:1 - Mini DC GearBox | 2 | SparkFun
Power supply unit | Breadboard Power Supply TS1171 | 1 | QITA
base plate | 305x305x15 mm | 1 | Holzland
Hall effect sensor | Module magnetic detector 49E LM393TS0145 | 1 | Eckstein Komponente
Microswitch red | XSS-5GL13 | 4 | amazon
Belt | T2 2mm pitch 6mm wide rubber timing belt | 2m | amazon
Linear ball bearing | LMU-N6 | 8 | Misumi
Push button | 15

∅

| / length 24 [mm] | 1 | amazon
Shafts | d6 x 300mm | 4 | Misumi
Storage box | | 1

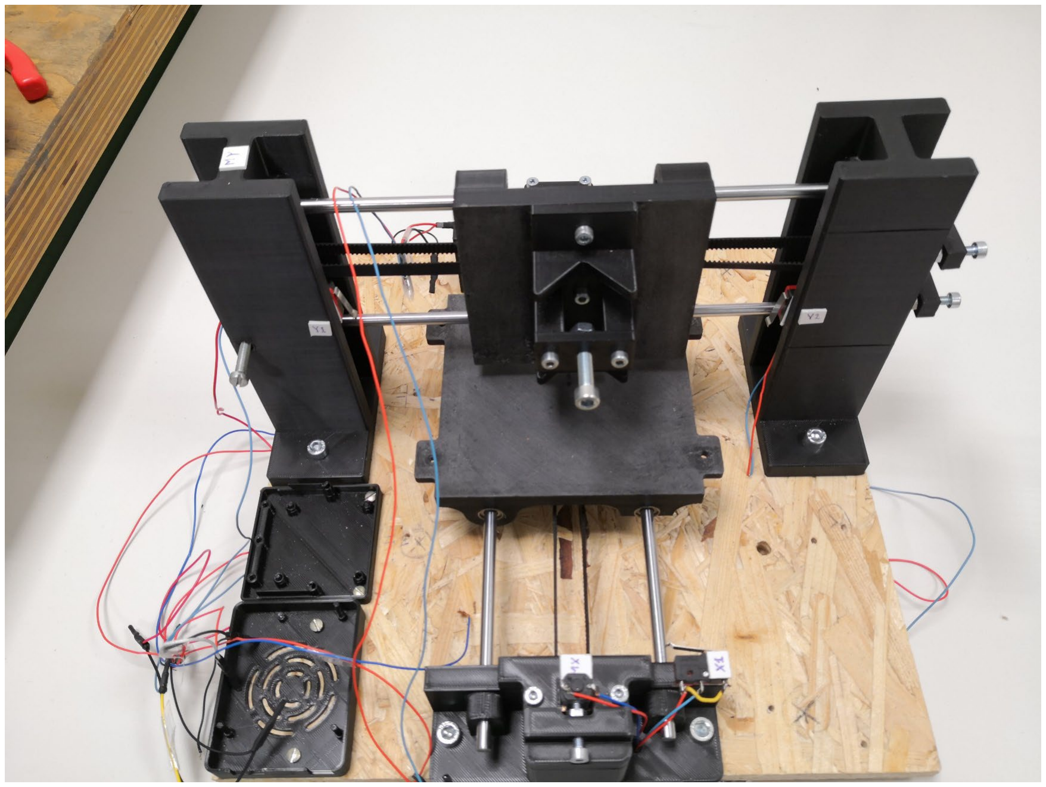
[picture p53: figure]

Folie 15

## Pen-Plotter

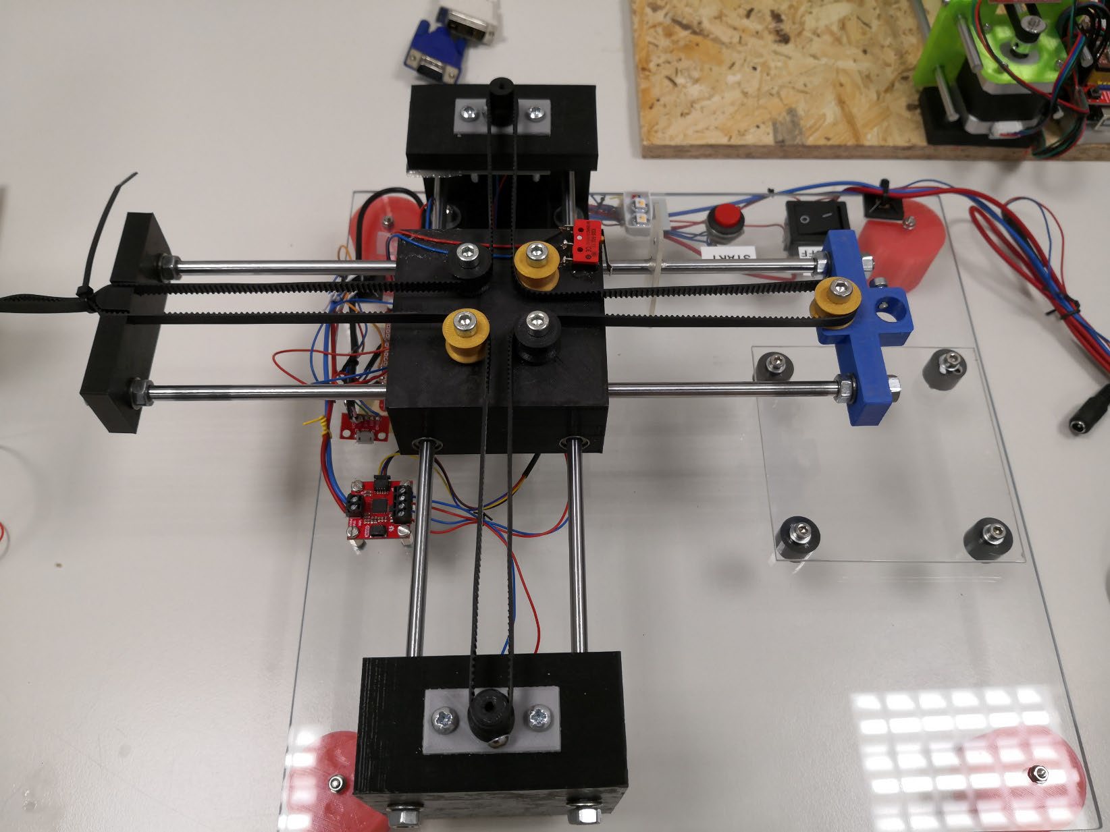
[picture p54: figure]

Folie 16

## Pen-Plotter

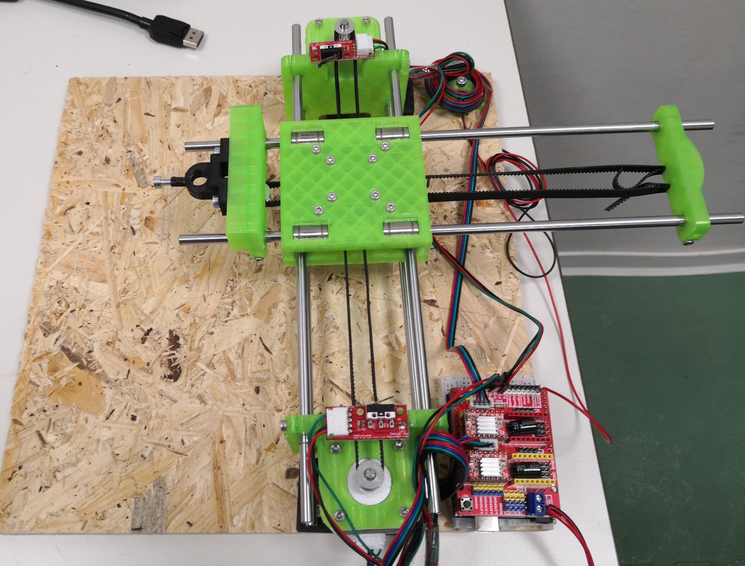
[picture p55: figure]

Folie 17

## Pen-Plotter

Folie 18

# Thank you for your attention

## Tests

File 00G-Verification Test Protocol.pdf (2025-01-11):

## Verification Test Protocol XY-Pen Plotter

XYPP_29_VerP.docx

Doc. # | XYPP_29_VerP

### Index of Change

Version | Description of Change | Name | Date
1.0 | Initial | Parul Vivek Sunder rao | 18-09-2023
2.0 | VerP #8 and #9 added | Pandaraboyana, Dheeraj Kumar | 25-09-2023
3.0 | VerP #10, #11, #12 and #13 added | Nitin Khule | 28-09-2023

### Table of Contents

### 1 Subject

Test item: XY Pen Plotter, Doc: # XYPP_29.xlsx

Report refers to Technical Specification doc: Group_29_Technical Specification. xlsb

A pen plotter is a computer-controlled device that utilizes pens or markers to generate precise and accurate drawings on paper. This project seeks to create a fully operational pen plotter by employing specific components and technologies. The objective is to demonstrate the seamless integration of hardware, software, and mechanical elements to accomplish a designated task.

The subsequent document outlines the validation process for the pen plotter constructed by Team #29 during the MERO 22/23 course. The assembly took place in the workshop module for pen plotters during the summer term of 2023. This document references the technical specifications, defining the requirements to be validated, and elucidates the corresponding verification routines and procedures, including the criteria and limits for verification.

The verification protocols are followed by subsequent verification tests, presenting the results in alignment with the protocols outlined in this document.

Name: | Parul Vivek Sunder Rao | Signature: | | Pandaraboyana, Dheeraj Kumar | Signature: |
Function: | Testing Engineer | | Manager Validation
Dep.: | MERO_Validation | | MERO_Validation

Date:

### 2 Verification Protocol

Verification Protocol

VerP # | ref to TS # | Test procedure (description of
routine) | Verification Criterion | Ref. # (i.e. test protocol, etc) | Domain (HW/SW/ME/ALL)

Application

VerP1 | TS5

Setup pen plotter on a stable surface.

Then draw Nikolaus house 10 times. | 10 Nikolaus Haus drawn | Group 29_Technical
Specification.xlsb | ALL

General Functions

VerP2 | TS1 | 56x42x39 cm provided by Uni Lab. Put the pen plotter into a box of | Fits in box with lid closed | Group 29_Technical Specification.xlsb | HW
VerP3 | TS1 | Place the pen plotter assembly on a measuring scale with an accuracy of ± 1gm. Take 3 readings and find out their mean value. | Mean of three weight measurement is well below 3500gm | Group 29_Technical Specification.xlsb | HW
VerP4 | TS1 | Run the Pen Plotter continuously across the paper for 30 min. | Continuous drawing upto 30 min at a time. | Group 29_Technical Specification.xlsb | ALL
Verification Test Protocol XY-Pen Plotter | Doc. # | XYPP_29_VerP
| Version: | 3.0
| Date: | 28-09-2023
| page: | 2 of 4
| Project #: | XYPP_29

General Functions

VerP5 | TS1 | Start stopwatch, activate plotter with button, run stopwatch concurrently. Stop timer after drawing completion. Take 3 readings and find out their mean value. | Average Time taken <40 seconds | Group 29_Technical Specification.xlsb | ALL
VerP6 | TS1 | Move the Pen from point A (0,0) to Point B (100,100) 10 times and measure the error at Point B for each cycle. | Average error <= ± 0.24mm | Group 29_Technical Specification.xlsb | ALL
VerP7 | TS1 | Start the pen plotter and take noise level measurement by sound level meter. Take 5 readings and find out their mean value. | Mean of three noise measurement is <=60 dBA | Group 29_Technical Specification.xlsb | HW/ME

Module Motor Controller Electronics and Wiring

VerP8 | TS8

Confirm switch functionality, halt plotter movement when contacted by levers, preventing overtravel and ensuring accurate and safe plotting. Check 10 times.

Overtravel prevention,
accurate and safe plotting.

Group 29_Technical
Specification.xlsb | HW

## XY-Pen Plotter

Date: | 28-09-2023
page: | 3 of 4
Project #: | XYPP_29

Module Base Plate

VerP9 | TS8

Align the plotter for accurate plotting within the maximum A4 size. Perform 10 test plot using an A4-sized drawing media.

Maximum size of drawing
media = A4.

Group 29_Technical
Specification.xlsb | HW

Module Pen Holder / Carriage
VerP10 | TS8 | Gather pens, position them and measure the diameter by Vernier callipers. Record the measurement results for each pen. | The diameter is less than 15mm | Group 29_Technical Specification.xlsb | ME
VerP11 | TS8 | Drawing media is positioned correctly, and maximum thickness of drawing media (wood base, etc) 3cm. | Maximum thickness of drawing media = 3cm. | Group 29_Technical Specification.xlsb | HW/ME

Module Coding, Control & User Interface

VerP12 | TS8

Power on, calibrate for accuracy (repeat 5 times), test emergency stop. Establish reliable starting point, align X and Y axis, move to specific point & check error.

Calibration (5 times), X and Y alignment, move to point,
check error and usage of
emergency stop.

Group 29_Technical
Specification.xlsb | SW

´
--End of Document--

## XY-Pen Plotter

Date: | 28-09-2023
page: | 4 of 4
Project #: | XYPP_29

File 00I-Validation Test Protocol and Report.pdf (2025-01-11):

Index of Change

Version | Description of Change | Name | Date
1.0 | Initial | Nitin Khule | 21-09-2023
2.0 | ValP #5 and #6 added | Rao, Parul Vivek Sunder | 25-09-2023
3.0 | ValP #7, #8 and #9 added | Pandaraboyana, Dheeraj Kumar | 28-09-2023
4.0 | ValP #10 and #11 added | Gangiredla, Varun Kumar | 02-10-2023

Table of Contents

### 1 Subject

Test item: | XY Pen Plotter, Doc: # XYPP_29_-Dossier
Report refers to Technical Specification doc: | Group_29_Technical Specification.xlsb

A pen plotter is a computer-controlled device that utilizes pens or markers to create accurate drawings on paper. This project seeks to construct a fully operational pen plotter by employing specific components and technologies, demonstrating the seamless integration of hardware, software, and mechanical elements to accomplish a defined task.

This document articulates the validation test protocols for assessing the pen plotter's performance.

The validation test protocols detailed in this document will establish a comprehensive framework for appraising the pen plotter's functionality, accuracy, and dependability.

Through the execution of these tests, our goal is to confirm the device's functionality and pinpoint any areas that may necessitate enhancement or optimization. The results derived from these tests will inform subsequent refinements to ensure the pen plotter aligns with the specified standards and serves as a dependable and precise drawing tool for users.

Validation Report XY-Pen Plotter XYPP_29_-ValP.docx | Doc. # | XYPP_29_ValR
| Version: | 4.0
| Date: | 02-10-2023
| page: | 1 of 5
| Project #: | XYPP_29
Name: | Parul Vivek Sunder Rao | Signature: | | Pandaraboyana, Dheeraj Kumar | Signature: |
Function: | Testing Engineer | | Manager Validation
Dep.: | MERO_Validation | | MERO_Validation

Date:

### 2 Validation Protocol

Validation Protocol

ValP # | ref. to UR # | Validation procedure (description of routine) | ref. # (i.e. validation protocol, customer test, etc..) | Validation criterion, target value
ValP1 | UR1, UR2, | Install the pen plotter in the university lab, initiate the pen plotter under the student's supervision, and proceed to create a drawing of Nikolaus Haus. | Group 29_Technical Specification.xlsb | Plotter must draw Nikolaus Haus in one run.
ValP2 | UR3 | Put the pen plotter into a box of 56x39x42 cm provided by Uni Lab. | Group 29_Technical Specification.xlsb | Fits perfectly
ValP3 | UR4 | Place the pen plotter assembly on a measuring scale with an accuracy of ± 1gm | Group 29_Technical Specification.xlsb | Total weight <= 3.5kg
ValP4 | UR3 | Continuous drawing up to 30 min at a time. | Group 29_Technical Specification.xlsb | 30 min.
ValP5 | UR4 | Compare the calculated mean value with expected results or specifications to ensure the accuracy of the timing measurements. | Group 29_Technical Specification.xlsb | Average error <= ±0.25mm
ValP6 | UR4 | Start the pen plotter and take noise level measurement by sound level meter. | Group 29_Technical Specification.xlsb | Average noise measure <=60 dBA

### Validation Report XY-Pen Plotter

Date: | 02-10-2023
page: | 2 of 5
Project #: | XYPP_29

ValP # | ref. to UR # | Validation procedure (description of routine) | ref. # (i.e. validation protocol, customer test, etc..) | Validation criterion, target value
ValP7 | UR4 | Validate the switch functionality through ten tests, ensuring the successful interruption of the plotter's movement upon contact with the levers. This verification process aims to prevent overtravel and guarantee precise, safe plotting. | Group 29_Technical Specification.xlsb | All the switches work properly.
ValP8 | UR3 | Maximum pen diameter of 15mm | Group 29_Technical Specification.xlsb | Pen diameter <=15mm
ValP9 | UR4 | Maximum thickness of drawing media = 3cm. | Group 29_Technical Specification.xlsb | Maximum thickness of drawing media >= 5mm.
| | Conduct a sequence of tests, encompassing initiation, calibration (repeated five times), emergency stop evaluation, determination of the starting point, alignment of the X and Y axes, movement to a designated point, and thorough error checking. | Group 29_Technical Specification.xlsb | All the functions are working properly.
ValP10 | UR4

### Validation Report XY-Pen Plotter

Doc. # | XYPP_29_-ValR
Date: | 02-10-2023
page: | 3 of 5
Project #: | XYPP_29

### 3 Validation Test Report

Validation Report

ValR # | ref. to ValP # | Criteria (passed/failed) | ref. # (i.e. test report, etc..)
ValR1 | ValP1 | Passed | Group 29_Technical Specification.xlsb
ValR2 | ValP2 | Passed | Group 29_Technical Specification.xlsb
ValR3 | ValP3 | Passed | Group 29_Technical Specification.xlsb
ValR4 | ValP4 | Passed | Group 29_Technical Specification.xlsb
ValR5 | ValP5 | Passed | Group 29_Technical Specification.xlsb
ValR6 | ValP6 | Passed | Group 29_Technical Specification.xlsb
ValR7 | ValP7 | Passed | Group 29_Technical Specification.xlsb
ValR8 | ValP9 | Passed | Group 29_Technical Specification.xlsb
ValR9 | ValP10 | Passed | Group 29_Technical Specification.xlsb

### Validation Report XY-Pen Plotter

Date: | 02-10-2023
page: | 4 of 5
Project #: | XYPP_29

### 4 Validation Test

The protocols provided in Section 2 (Validation Protocol) have undergone successful testing.

– end of document –

### Validation Report XY-Pen Plotter

Date: | 02-10-2023
page: | 5 of 5
Project #: | XYPP_29

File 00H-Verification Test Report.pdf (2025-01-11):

Index of Change

Version | Description of Change | Name | Date
1.0 | Initial | Parul Vivek Sunder rao | 21-09-2023
2.0 | Updated as per doc# XYPP_29_VerP | Pandaraboyana, Dheeraj Kumar | 25-09-2023
3.0 | Revised as per final review | Nitin Khule | 28-09-2023

Table of Contents

### 1 Subject

Test item: XY Pen Plotter, Doc: # XYPP_29

Report refers to Technical Specification doc: Group_29_Technical Specification.xlsb

A pen plotter, characterized as a computer-controlled apparatus employing pens or markers for creating precise and accurate drawings on paper, is the focus of this project. The goal is to develop a fully operational pen plotter by utilizing specific components and technologies that highlight the integration of hardware, software, and mechanical elements to accomplish a defined task.

This verification test report offers a comprehensive overview of the project, covering its background, design process, essential components and technologies, along with testing and performance evaluations. It makes reference to the technical specification, establishing the requirements slated for verification, and outlines the corresponding routines and procedures for verification, including the criteria and limits.

Within the contents of this report, a detailed exploration is undertaken of the specific tests carried out, their outcomes, and suggestions for further enhancements. Successful verification at the module level renders the product eligible for customer validation through a subsequent validation process.

Verification Test Report XY-Pen Plotter XYPP_29_VerR.docx | Doc. # | XYPP_29_VerR
| Version: | 3.0
| Date: | 28-09-2023
| page: | 1 of 4
| Project #: | XYPP_29
Name: | Parul Vivek Sunder Rao | Signature: | | Pandaraboyana, Dheeraj Kumar | Signature: |
Function: | Testing Engineer | | Manager Validation
Dep.: | MERO_Validation | | MERO_Validation

Date:

### 2 Verification Report

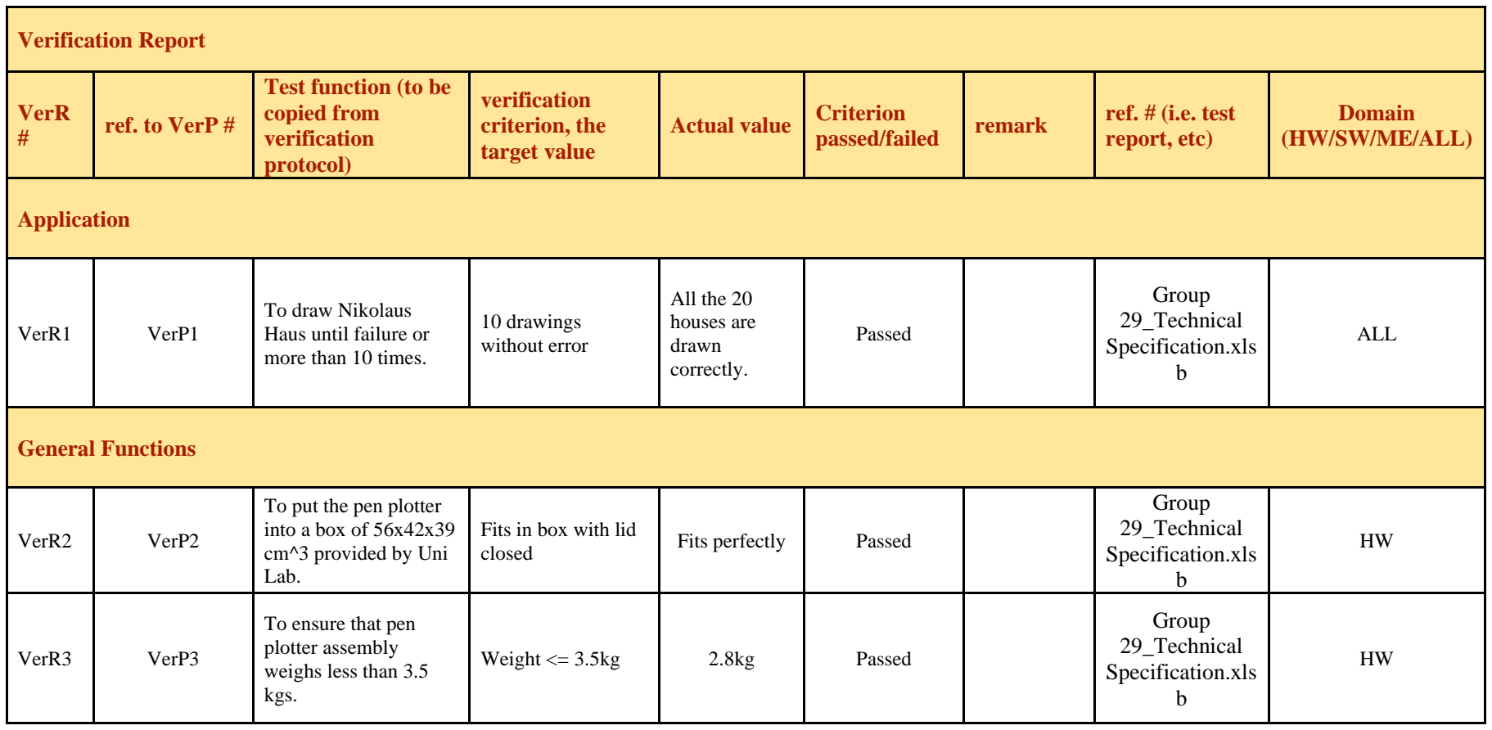
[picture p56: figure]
Verification Report; VerR #; ref. to VerP #; Test function (to be copied from verification protocol); verification criterion, the target value; Actual value; Criterion; passed/failed; remark; ref. # (i.e. test; report, etc); Domain (HW/SW/ME/ALL); Application; VerR1; VerP1; To draw Nikolaus Haus until failure or more than 10 times.; 10 drawings without error; All the 20 houses are drawn correctly.; Passed; Group 29_Technical Specification.xls b; ALL; General Functions

VerR2 | VerP2 | To put the pen plotter into a box of 56x42x39 cm^3 provided by Uni Lab. | Fits in box with lid closed | Fits perfectly | Passed | Group 29_Technical Specification.xls b | HW
VerR3 | VerP3 | To ensure that pen plotter assembly weighs less than 3.5 kgs. | Weight <= 3.5kg | 2.8kg | Passed | Group 29_Technical Specification.xls b | HW

### Verification Test Report XY-Pen Plotter

Date: | 28-09-2023
page: | 2 of 4
Project #: | XYPP_29

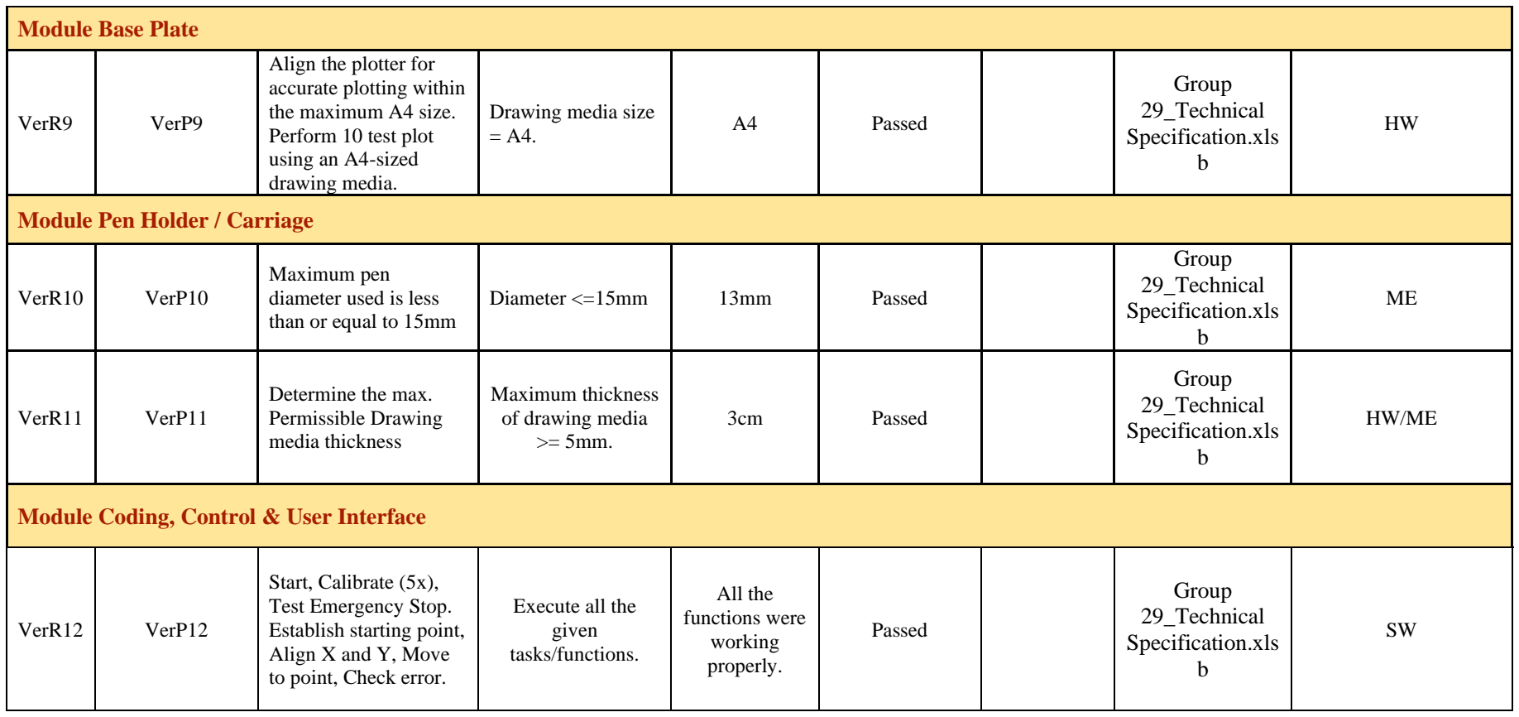
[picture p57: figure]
Module Base Plate; VerR9; VerP9; Align the plotter for accurate plotting within the maximum A4 size. Perform 10 test plot using an A4-sized drawing media.; Drawing media size; Passed; Group 29_Technical Specification.xls b; Module Pen Holder / Carriage; Module Coding, Control & User Interface; VerR12; VerP12; Start, Calibrate (5x), Test Emergency Stop. Establish starting point, Align X and Y, Move to point, Check error.; Execute all the given tasks/functions.; All the functions were working properly.

VerR10 | VerP10 | Maximum pen diameter used is less than or equal to 15mm | Diameter <=15mm | 13mm | Passed | Group 29_Technical Specification.xls b | ME
VerR11 | VerP11 | Determine the max. Permissible Drawing media thickness | Maximum thickness of drawing media >= 5mm. | 3cm | Passed | Group 29_Technical Specification.xls b | HW/ME

### Verification Test Report XY-Pen Plotter

Date: | 28-09-2023
page: | 3 of 4
Project #: | XYPP_29

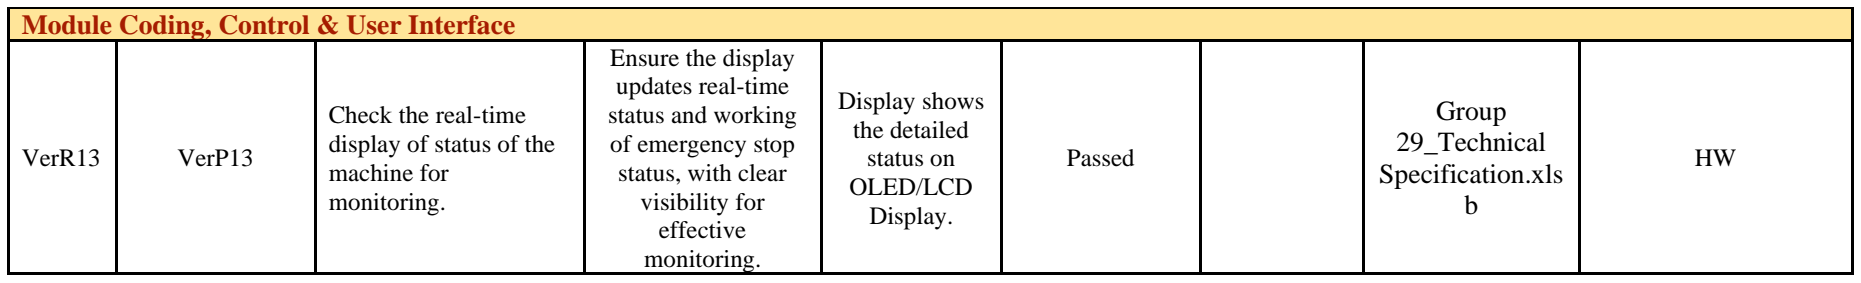
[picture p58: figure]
Module Coding, Control & User Interface; VerR13; VerP13; Check the real-time display of status of the machine for monitoring.; Ensure the display updates real-time status and working of emergency stop status, with clear visibility for effective monitoring.; Display shows the detailed status on OLED/LCD Display.; Passed; Group 29_Technical Specification.xls b

### 3 Final Evaluation

The verification has been passed successfully for all points.

– end of document –

### Verification Test Report XY-Pen Plotter

Date: | 28-09-2023
page: | 4 of 4
Project #: | XYPP_29
